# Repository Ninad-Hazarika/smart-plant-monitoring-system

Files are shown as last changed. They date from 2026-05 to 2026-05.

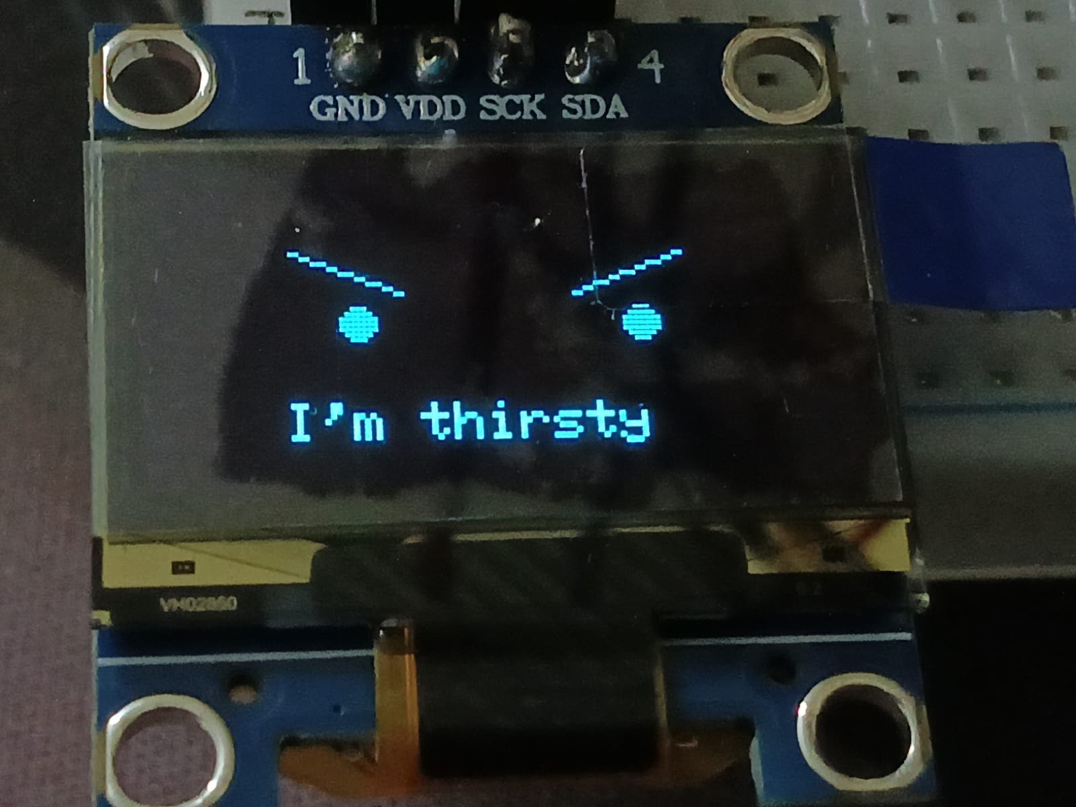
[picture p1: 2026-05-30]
smart-plant-monitoring-system/Images/thirsty_eyes.jpeg

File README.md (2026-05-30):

<div align="center">

```
 ██████╗ ██████╗ ███████╗███████╗███╗   ██╗    ██████╗ ██╗      █████╗ ███╗   ██╗████████╗
██╔════╝ ██╔══██╗██╔════╝██╔════╝████╗  ██║    ██╔══██╗██║     ██╔══██╗████╗  ██║╚══██╔══╝
██║  ███╗██████╔╝█████╗  █████╗  ██╔██╗ ██║    ██████╔╝██║     ███████║██╔██╗ ██║   ██║   
██║   ██║██╔══██╗██╔══╝  ██╔══╝  ██║╚██╗██║    ██╔═══╝ ██║     ██╔══██║██║╚██╗██║   ██║   
╚██████╔╝██║  ██║███████╗███████╗██║ ╚████║    ██║     ███████╗██║  ██║██║ ╚████║   ██║   
 ╚═════╝ ╚═╝  ╚═╝╚══════╝╚══════╝╚═╝  ╚═══╝    ╚═╝     ╚══════╝╚═╝  ╚═╝╚═╝  ╚═══╝   ╚═╝   
```

<h1>🌿 Smart Plant Monitoring System</h1>

**ESP32 · IoT · Telegram Alerts · Emotional OLED · Real-Time Web Dashboard**





[]()
[]()

<br/>

> *"Your plant now has feelings — and a Telegram account."*

<br/>

**A full-stack, sensor-fused plant care station** built on ESP32. It monitors soil moisture, ambient temperature & humidity, and water tank level in real time. It controls irrigation automatically or manually via a live web dashboard, fires Telegram push alerts for critical events, reacts to human presence via IR sensing, responds to touch gestures, and expresses five distinct emotions on an OLED face — complete with animated eyes.

</div>

---

## 🧠 System Architecture

```
╔══════════════════════════════════════════════════════════════════════════════╗
║                            SENSOR FUSION LAYER                               ║
║                                                                              ║
║  ┌──────────┐  ┌──────────┐  ┌──────────────┐  ┌──────────┐  ┌──────────┐  ║
║  │  DHT11   │  │   Soil   │  │  Ultrasonic  │  │    IR    │  │  Touch   │  ║
║  │ Temp/Hum │  │ Moisture │  │  HC-SR04     │  │ Detector │  │  Sensor  │  ║
║  │ GPIO 13  │  │ GPIO 34  │  │ TRIG:26 ECHO:25│ │ GPIO 33  │  │ GPIO 32  │  ║
║  └────┬─────┘  └────┬─────┘  └──────┬───────┘  └────┬─────┘  └────┬─────┘  ║
╚═══════╪═════════════╪═══════════════╪════════════════╪═════════════╪════════╝
        │             │               │                │             │
╔═══════▼═════════════▼═══════════════▼════════════════▼═════════════▼════════╗
║                          ESP32 DevKit (240 MHz)                              ║
║                                                                              ║
║   ┌─────────────────────────────────────────────────────────────────────┐   ║
║   │  Core 0: Wi-Fi Stack + WebServer + Telegram HTTPS Client            │   ║
║   │  Core 1: Sensor Reads · Pump Logic · OLED · IR/Touch · Buzzer      │   ║
║   │  ADC: 12-bit (0–4095) for soil moisture                            │   ║
║   │  I2C: GPIO 21 (SDA) / GPIO 22 (SCL) for OLED                      │   ║
║   └─────────────────────────────────────────────────────────────────────┘   ║
╚════════╪══════════════════════════════════╪═══════════════════════╪══════════╝
         │                                  │                       │
╔════════▼═══════════╗            ╔══════════▼═══════╗    ╔═════════▼══════════╗
║   OUTPUT LAYER     ║            ║   CONTROL LAYER  ║    ║  NOTIFICATION      ║
║                    ║            ║                  ║    ║  LAYER             ║
║  ┌──────────────┐  ║            ║  ┌────────────┐  ║    ║  ┌──────────────┐  ║
║  │  OLED 128×64 │  ║            ║  │   Relay    │  ║    ║  │  Telegram    │  ║
║  │  Emotions +  │  ║            ║  │  GPIO 15   │──╫──▶ ║  │  Bot Alerts  │  ║
║  │  Sensor data │  ║            ║  └─────┬──────┘  ║    ║  │  via HTTPS   │  ║
║  └──────────────┘  ║            ║        ▼          ║    ║  └──────────────┘  ║
║  ┌──────────────┐  ║            ║  ┌────────────┐  ║    ║  ┌──────────────┐  ║
║  │    Buzzer    │  ║            ║  │ Water Pump │  ║    ║  │  Web Server  │  ║
║  │  GPIO 27     │  ║            ║  │ (9V ext.)  │  ║    ║  │  Port 80     │  ║
║  └──────────────┘  ║            ║  └────────────┘  ║    ║  │  Dashboard   │  ║
╚════════════════════╝            ╚══════════════════╝    ║  └──────────────┘  ║
                                                          ╚════════════════════╝
```

---

## ✨ Feature Matrix

| Feature | Implementation | Status |
|---|---|:---:|
| 🌱 **Soil Moisture Sensing** | 12-bit ADC on GPIO 34, auto-threshold pump trigger | ✅ |
| 🌡️ **Temperature & Humidity** | DHT11 on GPIO 13, NaN-safe reads | ✅ |
| 💧 **Water Tank Level** | HC-SR04 ultrasonic, distance → level mapping | ✅ |
| 🖥️ **Live OLED Display** | Sensor data + 5 animated face emotions | ✅ |
| 🔌 **Relay Pump Control** | Active-LOW relay, 3 modes: AUTO / MANUAL ON / MANUAL OFF | ✅ |
| 🌐 **Local Web Dashboard** | ESP32-hosted HTTP server, auto-refresh every 2s | ✅ |
| 📱 **Mobile-Responsive UI** | Dark-theme dashboard, progress bars, live sensor cards | ✅ |
| 📲 **Telegram Bot Alerts** | HTTPS push alerts: low water, pump timeout, plant thirsty, human detected | ✅ |
| 👁️ **IR Human Detection** | GPIO 33 PIR/IR sensor, greeting emotion + Telegram ping | ✅ |
| 👆 **Triple-Touch Gesture** | GPIO 32 touch, 3 taps → LAUGHING emotion | ✅ |
| 🔔 **Buzzer Alert** | Beeps when water tank ≤ 3 cm | ✅ |
| 😊 **Emotion Engine** | 5 states: GREETING · HAPPY · SAD · LAUGHING · SLEEPY | ✅ |
| ⏱️ **Smart Alert Cooldowns** | 30s global Telegram cooldown, 5s human alert cooldown | ✅ |
| 🕐 **NTP Time Sync** | pool.ntp.org time sync on boot | ✅ |

---

## 😊 Emotion Engine

The OLED doesn't just show data — the plant *reacts* to the world around it.

```
┌─────────────────────────────────────────────────────────────────────────┐
│                         EMOTION STATE MACHINE                            │
│                                                                          │
│   IR detects human ──────────────────▶  GREETING  "Hello!"             │
│          │                               (3 sec)                        │
│          │                                                               │
│   Pump turns ON (auto or manual) ──────▶  HAPPY   "Ahh... Water!"      │
│                                            (3 sec)                       │
│                                                                          │
│   Water level ≤ 3 cm ──────────────────▶   SAD    "I'm thirsty"        │
│          │                               (3 sec, repeats every 10s)     │
│          │                                                               │
│   3 rapid touches (< 900ms apart) ─────▶ LAUGHING "Hehehe!"            │
│                                            (5 sec)                       │
│                                                                          │
│   No human for 60 seconds ─────────────▶  SLEEPY  "Zzz..."             │
│                                            (3 sec)                       │
│                                                                          │
│   Any emotion expires ─────────────────▶   NONE   [Sensor Data Screen] │
└─────────────────────────────────────────────────────────────────────────┘
```

### OLED Eye Animations

```
  OPEN EYES         HAPPY EYES        SAD EYES          SLEEPY EYES
  (Greeting)        (Watered)         (Thirsty)         (Idle 60s)

  ╭───╮ ╭───╮      ╱╲    ╱╲         ╲    ╱             ────  ────
  │ ● │ │ ● │     ╱  ╲  ╱  ╲         ╲  ╱                            Zz
  ╰───╯ ╰───╯                          ╲╱            (half-closed)
                                      • •
  LAUGHING
  ╱╲    ╱╲
 ╱  ╲  ╱  ╲    ←  happy eyes
  ╲──────╱      ←  wide grin
```

---

## 📲 Telegram Alert System

The bot fires push notifications directly to your phone. No polling — purely event-driven with smart cooldowns to prevent spam.

```
┌────────────────────────────────────────────────────────────────────┐
│                     ALERT TRIGGER CONDITIONS                        │
├─────────────────────────┬──────────────────────┬───────────────────┤
│ Alert                   │ Trigger Condition     │ Cooldown          │
├─────────────────────────┼──────────────────────┼───────────────────┤
│ 💧 Low Water            │ Tank level ≤ 3 cm     │ Once per event    │
│ ⚠️  Pump Running Long   │ Pump ON > 60 seconds  │ Once per event    │
│ 🌵 Plant Thirsty        │ Soil dry + pump OFF   │ Once per event    │
│                         │ for > 60 seconds      │                   │
│ 👤 Human Detected       │ IR sensor triggered   │ 5 seconds         │
│ ✅ System Online        │ On boot               │ Once              │
└─────────────────────────┴──────────────────────┴───────────────────┘
```

**Setup your Telegram bot:**

```
1. Open Telegram → search @BotFather
2. Send /newbot → follow prompts → copy your Bot Token
3. Add your bot to a group OR get your Chat ID via @userinfobot
4. Edit these lines in smart_plant_monitoring.ino:

   String botToken = "YOUR_BOT_TOKEN_HERE";
   String chatID   = "YOUR_CHAT_ID_HERE";
```

---

## 🌐 Web Dashboard

The ESP32 hosts a full dark-themed dashboard on port 80. No internet required — works entirely on your local Wi-Fi.

```
╔═══════════════════════════════════════════╗
║        SMART PLANT DASHBOARD              ║
║                        192.168.x.x        ║
╠═══════════════════════════════════════════╣
║  SENSORS                                  ║
║  ┌───────────────┐  ┌───────────────┐     ║
║  │ Soil Moisture │  │ Temperature   │     ║
║  │    2847       │  │   28.5 °C     │     ║
║  │ ████████░░░░  │  │ ██████░░░░░░  │     ║
║  └───────────────┘  └───────────────┘     ║
║  ┌───────────────┐  ┌───────────────┐     ║
║  │  Humidity     │  │ Water Level   │     ║
║  │   65.0 %      │  │   9.2 cm      │     ║
║  │ ████████████░ │  │ ████████████░ │     ║
║  └───────────────┘  └───────────────┘     ║
╠═══════════════════════════════════════════╣
║  PUMP CONTROL                             ║
║  Pump is OFF  ·  AUTO MODE                ║
║  ✅ System running normally               ║
║                                           ║
║  ╔══════╗  ╔══════╗  ╔══════╗            ║
║  ║  ON  ║  ║  OFF ║  ║ AUTO ║            ║
║  ╚══════╝  ╚══════╝  ╚══════╝            ║
╠═══════════════════════════════════════════╣
║  Auto-refreshes every 2 seconds           ║
╚═══════════════════════════════════════════╝

  Endpoints:
  GET /             → Full dashboard
  GET /pump/on      → Force pump ON  (MANUAL mode)
  GET /pump/off     → Force pump OFF (MANUAL mode)
  GET /pump/auto    → Return to AUTO mode
```

---
## 🎨 CAD Design

The complete enclosure and product body for the Smart Plant Monitoring System was designed using Onshape.

📁 View CAD Files Here → [CAD Design](./CAD-Design)

---
## 🛠️ Hardware & Bill of Materials

```
┌─────────────────────────────────────────────────────────────────────┐
│  COMPONENT                   │  QTY │  GPIO       │  PURPOSE        │
├──────────────────────────────┼──────┼─────────────┼─────────────────┤
│  ESP32 DevKit v1             │   1  │  —          │  MCU + Wi-Fi    │
│  DHT11 Sensor                │   1  │  GPIO 13    │  Temp + Humidity│
│  Capacitive Soil Sensor      │   1  │  GPIO 34    │  Soil moisture  │
│  HC-SR04 Ultrasonic          │   1  │  TRIG: 26   │  Tank level     │
│                              │      │  ECHO: 25   │                 │
│  OLED SSD1306 (0.96" I2C)   │   1  │  SDA: 21    │  Display/face   │
│                              │      │  SCL: 22    │                 │
│  5V Relay Module             │   1  │  GPIO 15    │  Pump switch    │
│  Mini DC Water Pump          │   1  │  (via relay)│  Irrigation     │
│  IR Obstacle/PIR Sensor      │   1  │  GPIO 33    │  Human detect   │
│  Touch Sensor Module         │   1  │  GPIO 32    │  Gesture input  │
│  Passive Buzzer              │   1  │  GPIO 27    │  Tank low alert │
│  9V Battery or DC Adapter    │   1  │  —          │  Pump power     │
│  USB Micro Cable             │   1  │  —          │  Program + 3.3V │
│  Jumper Wires (assorted)     │ ~30  │  —          │  Connections    │
│  Breadboard / Custom PCB     │   1  │  —          │  Assembly       │
└──────────────────────────────┴──────┴─────────────┴─────────────────┘
```

> **💡 Tip:** Use a **capacitive** soil moisture sensor over resistive — it doesn't corrode in wet soil and gives more stable analog readings.

---

## 🔌 Complete Pin Wiring Reference

```
                    ┌─────────────────────────┐
                    │       ESP32 DevKit       │
         DHT11 ────▶│ GPIO13          GPIO26  │────▶ HC-SR04 TRIG
    Soil Sensor ───▶│ GPIO34          GPIO25  │◀──── HC-SR04 ECHO
     Relay IN  ────▶│ GPIO15          GPIO27  │────▶ Buzzer (+)
      OLED SDA ────▶│ GPIO21          GPIO33  │◀──── IR Sensor OUT
      OLED SCL ────▶│ GPIO22          GPIO32  │◀──── Touch Sensor
          3.3V ────▶│ 3V3             GND     │────▶ Common GND
           VIN ────▶│ VIN (5V)                │
                    └─────────────────────────┘
```

| Peripheral | Signal | GPIO | Logic |
|---|---|:---:|---|
| **DHT11** | Data | `13` | 3.3V, add 10kΩ pull-up if needed |
| **Soil Sensor** | Analog OUT | `34` | Input-only ADC pin, 12-bit |
| **HC-SR04** | TRIG | `26` | 10µs pulse to trigger |
| **HC-SR04** | ECHO | `25` | pulseIn() measures duration |
| **OLED SSD1306** | SDA | `21` | I2C data, address 0x3C |
| **OLED SSD1306** | SCL | `22` | I2C clock |
| **Relay** | IN | `15` | Active LOW (RELAY_ON = LOW) |
| **IR Sensor** | OUT | `33` | LOW = human/object detected |
| **Touch Sensor** | OUT | `32` | HIGH = touch detected |
| **Buzzer** | + | `27` | digitalWrite HIGH to sound |

> ⚠️ **Critical:** Never power the water pump from ESP32 GPIO. Always use the relay as an isolated switch with a dedicated 9V supply. Connect the negative terminals (GND) of both supplies together.

---

## 📂 Repository Structure

```
smart-plant-monitoring-system/
│
├── 📄 README.md                        ← You are here
├── 📄 LICENSE                          ← MIT License
├── 📄 .gitignore
│
├── 📁 src/
│   ├── 🔧 smart_plant_monitoring.ino   ← Main firmware (FULL system)
│   ├── 🧪 pump_relay_test.ino          ← Isolated relay/pump test
│   └── 🧪 sensor_test.ino             ← DHT11 + soil sensor test
│
├── 📁 hardware/
│   ├── 📋 component_list.md            ← Full BOM with specs
│   └── 🔌 wiring_guide.md             ← Step-by-step connections
│
├── 📁 schematics/
│   └── 📐 README.md                   ← EasyEDA schematic notes
│
├── 📁 pcb/
│   └── 🖨️ README.md                   ← PCB design & fabrication guide
│
├── 📁 docs/
│   └── 📃 project_report.md           ← Technical project report
│
├── 📁 images/
│   └── 🖼️ (add project photos here)
│
└── 📁 website/
    └── 🌐 index.html                  ← Standalone web UI reference
```

---

## 📦 Required Arduino Libraries

Install via **Arduino IDE → Sketch → Include Library → Manage Libraries**:

```
┌─────────────────────────────────────────────────────────────────────┐
│  LIBRARY                     │  AUTHOR     │  PURPOSE               │
├──────────────────────────────┼─────────────┼────────────────────────┤
│  Adafruit GFX Library        │  Adafruit   │  OLED graphics engine  │
│  Adafruit SSD1306            │  Adafruit   │  OLED I2C driver       │
│  DHT sensor library          │  Adafruit   │  DHT11/22 driver       │
│  Adafruit Unified Sensor     │  Adafruit   │  Sensor abstraction    │
│  WiFi (built-in)             │  Espressif  │  Wi-Fi stack           │
│  WebServer (built-in)        │  Espressif  │  HTTP server           │
│  HTTPClient (built-in)       │  Espressif  │  Telegram HTTPS calls  │
│  WiFiClientSecure (built-in) │  Espressif  │  TLS/SSL for Telegram  │
└──────────────────────────────┴─────────────┴────────────────────────┘
```

**ESP32 Board Package** (add to Arduino IDE → Boards Manager URLs):
```
https://raw.githubusercontent.com/espressif/arduino-esp32/gh-pages/package_esp32_index.json
```

---

## 🚀 Getting Started

### 1. Clone the Repository

```bash
git clone https://github.com/YOUR_USERNAME/smart-plant-monitoring-system.git
cd smart-plant-monitoring-system
```

### 2. Configure Credentials

Open `src/smart_plant_monitoring.ino` and edit these lines:

```cpp
// Wi-Fi credentials
const char* ssid     = "YOUR_WIFI_NAME";
const char* password = "YOUR_WIFI_PASSWORD";

// Telegram bot (see Telegram Setup section above)
String botToken = "YOUR_BOT_TOKEN";
String chatID   = "YOUR_CHAT_ID";

// Calibration
int threshold   = 3000;    // ADC value above which soil is "dry"
float tankHeight = 13.7;   // Height of your water tank in cm
```

### 3. Upload to ESP32

```
1. Open src/smart_plant_monitoring.ino in Arduino IDE
2. Tools → Board → ESP32 Arduino → "ESP32 Dev Module"
3. Tools → Port → Select your COM port
4. Tools → Upload Speed → 115200
5. Click Upload ▶
6. Open Serial Monitor at 115200 baud
7. Wait for "WiFi Connected" and note the IP address
8. Open that IP in any browser on the same Wi-Fi
```

### 4. Test Components Individually

Before running the full system, verify hardware with isolated tests:

```
Relay/Pump Test:   src/pump_relay_test.ino
                   → Pump toggles ON/OFF every 3 seconds

Sensor Test:       src/sensor_test.ino
                   → Soil, temperature, humidity printed to Serial every 1s
```

---

## ⚙️ Pump Control Modes

```
┌──────────────────────────────────────────────────────────────────┐
│  MODE         │  BEHAVIOR                          │  pumpMode   │
├───────────────┼────────────────────────────────────┼─────────────┤
│  AUTO         │  Pump ON if soilValue > threshold  │     0       │
│               │  Pump OFF when soil is moist again │             │
├───────────────┼────────────────────────────────────┼─────────────┤
│  MANUAL ON    │  Pump forced ON regardless of soil │     1       │
│               │  HAPPY emotion triggered on switch │             │
├───────────────┼────────────────────────────────────┼─────────────┤
│  MANUAL OFF   │  Pump forced OFF regardless        │     2       │
└───────────────┴────────────────────────────────────┴─────────────┘
```

---

## 📈 Sensor Data Reference

### Soil Moisture ADC Scale (GPIO 34, 12-bit)

```
  WET  ░░░░░░░░░░░░░░░░░████████████████  0    – 1500
  MOIST░░░░░░░░████████████████░░░░░░░░░  1500 – 3000
  DRY  ████████████████████░░░░░░░░░░░░░  3000 – 4095  ← pump triggers here

  Default dryThreshold = 3000  (calibrate for your soil + sensor type)
  Lower reading = more water in soil (inverse relationship)
```

### DHT11 Operating Ranges

```
  Temperature :  0°C – 50°C    (±2°C accuracy)
  Humidity    :  20% – 90% RH  (±5% accuracy)
  Sample rate :  1 Hz max       (1 reading/second)
  Power       :  3.3V or 5V
```

### HC-SR04 Water Level Formula

```
  distance (cm) = pulseIn(ECHO, HIGH) × 0.034 / 2
  waterLevel    = tankHeight − distance

  tankHeight = physical height of tank (default: 13.7 cm)
  waterLevel = 0 when empty, tankHeight when full
  Alert fires when waterLevel ≤ 3 cm
```

---

## 🧠 Firmware Loop Overview

```
BOOT
 │
 ├─ Init: Serial, GPIO, DHT, OLED, Wi-Fi, WebServer, NTP
 ├─ Send Telegram: "SMART_PLANT_SYSTEM_ONLINE"
 │
 └─ LOOP (every 50ms)
      │
      ├─ server.handleClient()         ← serve web dashboard requests
      │
      ├─ handleIR()                    ← detect human → GREETING emotion
      ├─ handleTouch()                 ← 3 taps → LAUGHING emotion
      │
      └─ (every 1000ms)
           ├─ readSoil()               ← ADC read GPIO 34
           ├─ readDHT()                ← temperature + humidity
           ├─ readWaterLevel()         ← HC-SR04 pulse timing
           ├─ controlPump()            ← AUTO / MANUAL logic + relay
           ├─ checkTankLevel()         ← buzzer beep if water ≤ 3cm
           ├─ updateOLED()             ← emotion or sensor data screen
           └─ checkTelegramAlerts()    ← push alerts with cooldowns
```

---

## 🔭 Roadmap

- [x] Soil moisture sensing + auto pump control
- [x] DHT11 temperature & humidity
- [x] HC-SR04 water tank level monitoring
- [x] OLED animated emotion display
- [x] Relay pump: AUTO / MANUAL ON / MANUAL OFF modes
- [x] Local Wi-Fi web dashboard (dark theme, auto-refresh)
- [x] Telegram bot alerts (low water, pump timeout, thirsty, human)
- [x] IR human detection + greeting emotion
- [x] Triple-touch gesture → laughing emotion
- [x] Buzzer low-water alert
- [x] NTP time synchronization
- [ ] MQTT / Home Assistant integration
- [ ] Data logging to SD card or Firebase
- [ ] OTA (Over-The-Air) firmware updates
- [ ] Battery backup with solar charging
- [ ] Custom PCB with enclosure
- [ ] Daily summary Telegram report

---

## 🤝 Contributing

1. Fork the repository
2. Create a feature branch: `git checkout -b feature/mqtt-integration`
3. Commit your changes: `git commit -m 'Add MQTT support for Home Assistant'`
4. Push the branch: `git push origin feature/mqtt-integration`
5. Open a Pull Request

---

## 👤 Author

**Ninad Hazarika**  
📧 [ninadhazarika@gmail.com](mailto:ninadhazarika@gmail.com)  
🌍 Built with curiosity, an ESP32, and a slightly dramatic plant 🌱

---

## 📜 License

This project is licensed under the **MIT License** — see the [LICENSE](./LICENSE) file for details.

---

<div align="center">

**⭐ Found this useful? Star the repo and share it with a fellow plant parent!**

```
        .     .
       /|\   /|\
      / | \ / | \
     /  |  X  |  \
    / 🌡️ |/ \| 💧 \
   /    |   |    \
  /_____|___|_____\
  | 🌿 SMART  🌿 |
  |  PLANT LOVE  |
  |______________|
```

*For every plant that ever wilted because no one was watching.*  
*Not anymore.* 🌿

</div>

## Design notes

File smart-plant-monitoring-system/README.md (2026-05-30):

# 🌱 Smart Plant Monitoring System

A smart IoT-based plant monitoring and irrigation system developed using ESP32. The project monitors environmental conditions such as soil moisture, temperature, and humidity, and can automatically control water supply to plants when required.

## 📌 Features

* Real-time soil moisture monitoring
* Temperature and humidity sensing using DHT11
* Automatic irrigation using relay-controlled water pump
* OLED display for local monitoring
* Human detection alerts using IR sensor
* Wi-Fi connectivity through ESP32
* Telegram notifications for remote monitoring
* Custom PCB design for hardware integration
* 3D CAD enclosure design for project assembly

## 🛠️ Hardware Components

* ESP32 Development Board
* Soil Moisture Sensor
* DHT11 Temperature & Humidity Sensor
* OLED Display (128×64)
* Relay Module
* Mini Water Pump
* IR Sensor
* LEDs and Resistors
* Power Supply
* Connecting Wires

## 💻 Software & Tools

* Arduino IDE
* EasyEDA (Schematic & PCB Design)
* Onshape (CAD Design)
* Git & GitHub

## 📂 Repository Structure

├── Arduino-Code
├── PCB-Design
├── CAD-Design
├── Images
├── Project-Report
└── README.md

## ⚙️ Working Principle

The soil moisture sensor continuously monitors the moisture level of the soil. When the moisture level drops below a predefined threshold, the ESP32 activates a relay that powers the water pump and irrigates the plant automatically.

Environmental data from the DHT11 sensor is displayed on the OLED screen. The system can also send notifications through Telegram and provide remote monitoring capabilities via Wi-Fi.

## 📸 Project Gallery

Screenshots, hardware setup images, PCB layouts, CAD models, and demonstration photographs can be found in the Images folder.

## 🚀 Future Improvements

* Mobile application integration
* Cloud-based data logging
* Weather-aware irrigation scheduling
* AI-powered plant health monitoring
* Battery and solar-powered operation

## 👨‍💻 Author

Ninad Hazarika

Electronics and Communication Engineering Student

Tezpur University

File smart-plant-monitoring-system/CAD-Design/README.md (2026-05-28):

# 🌱 Smart Plant Monitoring System - CAD Design

This folder contains the complete CAD design and enclosure development for the Smart Plant Monitoring System created using Onshape.

---

## 📌 Design Objectives

- Create a compact smart planter enclosure
- Integrate electronics safely inside the body
- Design dedicated water tank placement
- Create proper routing space for wiring
- Ensure easy accessibility for maintenance
- Build an aesthetic and functional product design

---

## 🛠 Designed Components

### 🌿 Plant Holder
- Dedicated space for soil and plant placement
- Stable and compact structure

### 💧 Water Tank
- Separate compartment for water storage
- Optimized for mini water pump integration

### ⚡ Electronics Section
- Placement for:
  - ESP32
  - Relay Module
  - Soil Moisture Sensor
  - DHT11 Sensor
  - OLED Display
  - Wiring Management

### 🔩 Enclosure Design
- Compact all-in-one body
- Practical layout for real-world usage

---

## 🧰 Software Used

- Onshape CAD

---

## 📂 Included Files

| File Type | Description |
|---|---|
| `.STEP` | Complete 3D assembly |
| `.STL` | 3D printable model |
| `.PNG` | Design previews and renders |

---

## 📸 CAD Preview

### Full Assembly
Full Assembly

### Exploded View
Exploded View

### Electronics Placement
Electronics

---

## 🚀 Future Improvements

- Waterproof enclosure
- Better cable management
- Modular sensor slots
- Optimized 3D printable design

---

## 👨‍💻 Developed By

Ninad Hazarika

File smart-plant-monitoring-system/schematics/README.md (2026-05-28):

# Schematics

Circuit schematics for the Smart Plant Monitoring System were designed using [EasyEDA](https://easyeda.com/).

## Files Added

| Format | Use |
|---|---|
| `.svg` | Preview in GitHub directly |
| `.json` | EasyEDA native project file |
| `.pdf` | High-res printable schematic |
| `.png` | Quick documentation embed |

## Key Connections Summary

- **DHT11** → GPIO 13 (data), 3.3V, GND
- **Soil Sensor** → GPIO 34 (analog), 3.3V, GND
- **OLED SSD1306** → GPIO 21 (SDA), GPIO 22 (SCL), 3.3V, GND
- **Relay** → GPIO 15 (IN), 5V/VIN, GND
- **Pump** → Relay COM/NO terminals, powered by external 9V supply

See `hardware/wiring_guide.md` for the complete step-by-step guide.

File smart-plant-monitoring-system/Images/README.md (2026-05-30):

# Images

This directory contains screenshots, photographs, PCB layouts, CAD designs, and demonstration images for the Smart Plant Monitoring System project.

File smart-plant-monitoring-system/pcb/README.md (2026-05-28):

# PCB Design

Custom PCB layout for the Smart Plant Monitoring System.

## Design Tool

PCB was designed in [EasyEDA](https://easyeda.com/) — free, browser-based, with direct JLCPCB/PCBWay ordering integration.

## Files Added Here

| File | Description |
|---|---|
| `pcb_design.json` | EasyEDA PCB project file |
| `gerber.zip` | Gerber files for PCB fabrication |
| `pcb_top.png` | Top layer render |
| `pcb_bottom.png` | Bottom layer render |

## PCB Ordering

Export Gerber files from EasyEDA and upload to:
- [JLCPCB](https://jlcpcb.com/) — ~$2 for 5 PCBs
- [PCBWay](https://www.pcbway.com/)

## Design Notes

- Ensure relay footprint matches your specific relay module dimensions
- Add decoupling capacitor (100nF) near ESP32 3.3V pin
- Route I2C lines (SDA/SCL) with short traces to minimize interference
- Separate pump power ground from ESP32 signal ground if possible

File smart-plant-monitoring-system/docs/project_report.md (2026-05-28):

# Project Report: Smart Plant Monitoring System

## Introduction

This project is an ESP32-based smart plant monitoring and irrigation system. It reads soil moisture, temperature, and humidity, displays values on an OLED screen, and controls a water pump through a relay.

## Objective

The goal is to create a low-cost plant care system that can help monitor plant health and automate watering.

## Methodology

1. Connect sensors to ESP32.
2. Read sensor values using Arduino IDE.
3. Display readings on OLED.
4. Control pump using relay.
5. Add Wi-Fi web interface for phone-based control.
6. Design schematic and PCB using EasyEDA.

## Result

The system successfully reads sensor values and allows pump control through a local web page.

## Conclusion

This project helped demonstrate the use of ESP32, sensors, relay modules, OLED display, and basic IoT control.

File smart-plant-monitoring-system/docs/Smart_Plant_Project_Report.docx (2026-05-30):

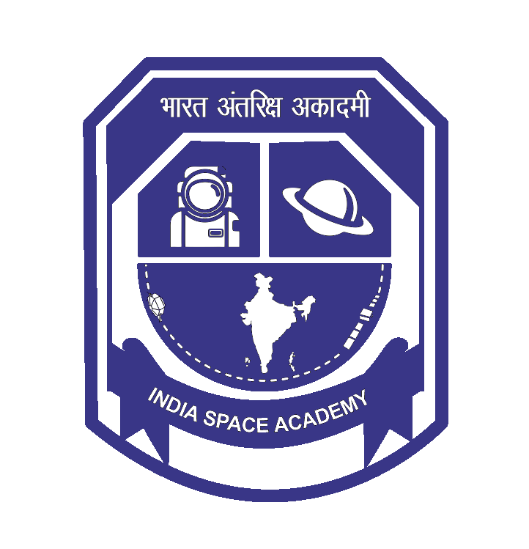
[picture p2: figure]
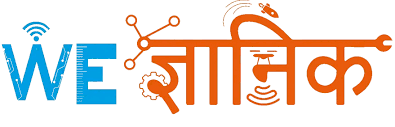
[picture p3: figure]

PROJECT REPORT

Smart Plant Monitoring System

ESP32-Powered IoT Plant Care & Automation System

Author | Ninad Hazarika
Email | ninadhazarika@gmail.com
IDE | Arduino IDE 2.x
Language | C++ (Arduino Framework)
Version | v2.0 — 2026
License | MIT Open Source

https://github.com/Ninad-Hazarika/smart-plant-monitoring-system

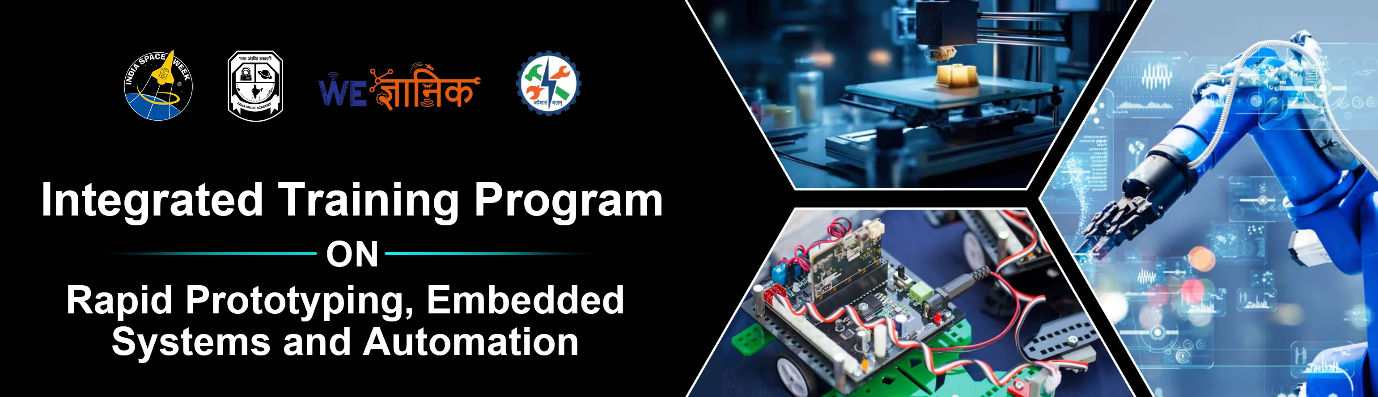
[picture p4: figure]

# 1. Project Title & Introduction

## 1.1 Project Title

Smart Plant Monitoring System using ESP32

## 1.2 Introduction

Modern agriculture and home gardening face a persistent challenge: plants are frequently over-watered, under-watered, or neglected due to busy schedules and the absence of objective feedback. Traditional plant care relies entirely on human observation — a method prone to error, inconsistency, and forgetfulness.

This project presents a fully autonomous, IoT-enabled Smart Plant Monitoring System built on the ESP32 microcontroller. The system continuously measures soil moisture, ambient temperature and humidity, and water tank level. It drives a relay-controlled irrigation pump automatically based on configurable soil dryness thresholds, hosts a live dark-theme web dashboard accessible from any browser on the local network, and fires real-time push alerts directly to the user's Telegram account for five distinct critical events.

Beyond pure telemetry, the system incorporates a personality layer: an OLED display renders animated facial expressions that react to environmental conditions and human presence — greeting visitors through IR detection, expressing happiness when watered, sadness when the tank runs low, and playful laughter when a triple-touch gesture is detected.

Key Highlights at a Glance:

• 9 peripherals fused on a single ESP32 — sensors, actuators, display, network

• Three pump modes: AUTO (soil-threshold) / MANUAL ON / MANUAL OFF

• 5-state animated OLED emotion engine

• Real-time Telegram bot push alerts over HTTPS

• Local Wi-Fi web dashboard — no cloud required

# 2. Problem Statement

The following core problems motivate the design of this system:

- Inconsistent manual watering causes root rot (over-watering) or wilting (under-watering), both of which cause lasting damage to plant health.
- The absence of real-time sensor feedback means the user has no objective data to inform watering decisions.
- Water tank depletion goes undetected — automated pump systems run dry, damaging the pump and failing to irrigate the plant.
- No alert mechanism means problems are only discovered after visible damage has already occurred.
- Human presence near sensitive plants goes unlogged, which matters in shared spaces or research environments.

The proposed solution addresses all five problems through sensor fusion, rule-based automation, and real-time communication — requiring zero manual intervention under normal operating conditions.

# 3. Components Used

## 3.1 Bill of Materials

Component | Specification | Qty | GPIO / Interface | Purpose
ESP32 DevKit v1 | Dual-core LX6, 240 MHz, Wi-Fi + BT | 1 | — | Main MCU + network
DHT11 Sensor | 0-50 C, 20-90% RH, digital 1-wire | 1 | GPIO 13 | Temp & humidity
Soil Moisture Sensor | Capacitive, analog, 3.3V | 1 | GPIO 34 (ADC) | Soil wetness 0-4095
HC-SR04 Ultrasonic | 2-400 cm, +/-3 mm, 5V | 1 | TRIG:26 ECHO:25 | Water tank level
OLED SSD1306 | 0.96", 128x64 px, I2C, 3.3V | 1 | SDA:21 SCL:22 | Live display + face
5V Relay Module | Single ch., active LOW, 10A/250VAC | 1 | GPIO 15 | Pump switching
Mini DC Water Pump | 3-6V, submersible, ~100 L/h | 1 | Via relay | Irrigation
IR Obstacle Sensor | Digital OUT, adjustable detection range | 1 | GPIO 33 | Human detection
Touch Sensor (TTP223) | Capacitive, digital OUT, 3.3-5V | 1 | GPIO 32 | Gesture input
Passive Buzzer | 5V, ~2 kHz | 1 | GPIO 27 | Low-water alert
9V Adapter / Battery | Isolated pump supply | 1 | — | Pump power
USB Micro Cable | Programming + ESP32 power | 1 | — | Development
Jumper Wires | M-M / M-F assorted | ~30 | — | Wiring
Breadboard / PCB | 830-point or custom EasyEDA PCB | 1 | — | Assembly

## 3.2 Library Dependencies

Library | Author | Purpose
Adafruit GFX Library | Adafruit | OLED graphics primitives (circles, lines, text)
Adafruit SSD1306 | Adafruit | SSD1306 OLED driver over I2C
DHT sensor library | Adafruit | DHT11 / DHT22 one-wire protocol driver
Adafruit Unified Sensor | Adafruit | Unified hardware abstraction layer
WiFi (built-in) | Espressif | Wi-Fi station mode and connection management
WebServer (built-in) | Espressif | HTTP server on port 80 for web dashboard
HTTPClient (built-in) | Espressif | HTTPS GET client for Telegram Bot API
WiFiClientSecure (built-in) | Espressif | TLS/SSL transport for Telegram HTTPS calls

# 4. Working Explanation

## 4.1 System Boot Sequence

On power-up the ESP32 initialises all GPIO pins, starts the DHT11 driver, initialises the OLED display and shows a startup message, connects to Wi-Fi, synchronises time via NTP (pool.ntp.org), starts the HTTP web server on port 80, and transmits a 'System Online' Telegram notification. The full boot sequence completes in approximately 5-7 seconds.

## 4.2 Main Execution Loop

The main loop executes with a 50 ms base delay. Work is divided into per-loop and per-second tasks:

### Every iteration (50 ms):

- server.handleClient() — serves incoming HTTP requests from browsers
- handleIR() — polls GPIO 33; detects human presence on LOW signal; triggers GREETING emotion on rising edge
- handleTouch() — polls GPIO 32; tracks rapid triple-tap within 900 ms window to trigger LAUGHING emotion

### Every 1000 ms (sensor cycle):

- readSoil() — 12-bit ADC read on GPIO 34 (higher value = drier soil)
- readDHT() — reads temperature and humidity from DHT11 with NaN protection
- readWaterLevel() — sends 10 µs TRIG pulse; measures ECHO duration; computes: waterLevel = tankHeight - (duration x 0.034 / 2)
- controlPump() — evaluates pumpMode and drives relay accordingly; triggers HAPPY on pump start
- checkTankLevel() — pulses buzzer on GPIO 27 if waterLevel is at or below 3 cm
- updateOLED() — renders active emotion face or sensor data screen
- checkTelegramAlerts() — evaluates all five alert conditions with independent cooldown timers

## 4.3 Pump Control Modes

Mode | pumpMode | Behaviour | Emotion
AUTO | 0 | Pump ON when soilValue > threshold; OFF when moist again | HAPPY when pump first turns ON
MANUAL ON | 1 | Pump forced ON regardless of soil moisture reading | HAPPY immediately
MANUAL OFF | 2 | Pump forced OFF regardless of soil moisture reading | None

## 4.4 OLED Emotion Engine

The emotion engine uses a priority system: when currentEmotion is not NONE, the OLED renders the face animation. When emotionUntil is exceeded (millis() > emotionUntil), the system returns to NONE and the sensor data screen is shown. Emotion drawing uses Adafruit GFX primitives on the 128x64 pixel canvas.

Emotion | Trigger | Duration | OLED Text
GREETING | IR sensor detects object (rising edge on GPIO 33) | 3 seconds | Hello!
HAPPY | Pump turns ON (auto threshold or manual) | 3 seconds | Ahh... Water!
SAD | Water level at or below 3 cm (repeats every 10s) | 3s per cycle | I'm thirsty
LAUGHING | 3 touch events within 900 ms on GPIO 32 | 5 seconds | Hehehe!
SLEEPY | No IR trigger for 60+ consecutive seconds | 3 seconds | Zzz...
NONE | Any emotion timer expires (emotionUntil exceeded) | Until next event | [Sensor Data Screen]

## 4.5 Telegram Alert System

Alerts are delivered using WiFiClientSecure with setInsecure() to establish TLS sessions with api.telegram.org without certificate pinning. All message text is URL-encoded before embedding in the GET request URL. Five independent alert conditions are checked on every sensor cycle:

Alert | Trigger Condition | Cooldown | Auto-Reset When
System Online | Boot completes | Once | N/A
Low Water | waterLevel at or below 3 cm | Per event | waterLevel > 5 cm
Pump Overtime | Pump ON for more than 60 continuous seconds | Per event | Pump turns OFF
Plant Thirsty | soilValue > threshold AND pump OFF for 60s+ | Per event | Moist OR pump ON
Human Detected | IR LOW for 2+ consecutive loop polls | 5 seconds | IR returns HIGH

## 4.6 Web Dashboard

The ESP32 hosts a single-page dark-theme dashboard on port 80. Sensor values are embedded server-side at render time. The page auto-refreshes every 2 seconds via JavaScript setTimeout(). Pump mode changes are handled as HTTP 303 redirects. The dashboard is fully responsive and works on any mobile or desktop browser on the same Wi-Fi network.

# 5. Circuit Diagram

## 5.1 Complete GPIO Pin Assignment

Peripheral | Peripheral Pin | ESP32 Pin | Signal | Notes
DHT11 | Data OUT | GPIO 13 | Digital 1-wire | Add 10k pull-up if no onboard resistor
DHT11 | VCC | 3.3V | Power
DHT11 | GND | GND | Ground
Soil Sensor | AO | GPIO 34 | Analog ADC | Input-only pin; 12-bit resolution
Soil Sensor | VCC | 3.3V | Power
HC-SR04 | TRIG | GPIO 26 | Digital OUT | 10 µs HIGH pulse to trigger
HC-SR04 | ECHO | GPIO 25 | Digital IN | Use voltage divider if module outputs 5V
OLED SSD1306 | SDA | GPIO 21 | I2C Data | I2C address 0x3C
OLED SSD1306 | SCL | GPIO 22 | I2C Clock
OLED SSD1306 | VCC | 3.3V | Power
Relay Module | IN | GPIO 15 | Digital OUT | Active LOW — RELAY_ON = LOW
Relay Module | VCC | VIN (5V) | Power | Must use 5V, not 3.3V
IR Sensor | OUT | GPIO 33 | Digital IN | LOW = object/human detected
Touch Sensor | OUT | GPIO 32 | Digital IN | HIGH = touch detected
Buzzer | Positive | GPIO 27 | Digital OUT | HIGH = buzzer sounds

## 5.2 Power & Safety Notes

- CRITICAL: Never connect the water pump directly to any ESP32 GPIO pin. The relay provides full galvanic isolation between the 3.3V control circuit and the 9V pump circuit.
- Connect the negative terminal (GND) of the 9V pump supply to the ESP32 GND to create a common ground reference.
- GPIO 34 is an ADC input-only pin — do not attempt to configure it as OUTPUT.
- The HC-SR04 ECHO pin on some modules outputs 5V logic. Use a 1k/2k voltage divider before GPIO 25 to avoid damaging the ESP32.

Schematic & PCB files:

• EasyEDA schematic (.json, .svg) — available in /schematics/ on GitHub

• PCB layout and Gerber files for fabrication — available in /pcb/ on GitHub

• PCB can be ordered from JLCPCB for approximately $2 USD per 5 boards

# 6. Source Code

## 6.1 Repository File Structure

File / Folder | Description
src/smart_plant_monitoring.ino | Main firmware — complete system with all 9 peripherals
src/pump_relay_test.ino | Isolated relay and pump test (toggles every 3 seconds)
src/sensor_test.ino | DHT11 + soil sensor diagnostic (Serial Monitor output)
hardware/component_list.md | Full BOM with specifications and sourcing information
hardware/wiring_guide.md | Step-by-step connection guide for each peripheral
schematics/ | EasyEDA circuit schematic files (.json, .svg)
pcb/ | PCB layout and Gerber files for board fabrication
docs/ | Project report (this document) and technical notes
website/index.html | Standalone web dashboard UI reference file
README.md | Full technical documentation and quick-start guide

## 6.2 Key Code Sections

### Water Level Measurement — HC-SR04

void readWaterLevel() {

digitalWrite(TRIG_PIN, LOW);

delayMicroseconds(2);

digitalWrite(TRIG_PIN, HIGH); // trigger 10us pulse

delayMicroseconds(10);

digitalWrite(TRIG_PIN, LOW);

long duration = pulseIn(ECHO_PIN, HIGH, 30000); // 30ms timeout

if (duration == 0) { waterLevel = -1; return; } // no echo = error

float distance = duration * 0.034 / 2; // convert to cm

waterLevel = tankHeight - distance; // invert: less distance = more water

if (waterLevel < 0) waterLevel = 0;

}

### Three-Mode Pump Control

void controlPump() {

bool oldState = pumpState;

if (pumpMode == 1) { digitalWrite(RELAY_PIN, RELAY_ON); pumpState = true; }

else if (pumpMode == 2) { digitalWrite(RELAY_PIN, RELAY_OFF); pumpState = false; }

else { // AUTO — soil threshold control

if (soilValue > threshold) { digitalWrite(RELAY_PIN, RELAY_ON); pumpState = true; }

else { digitalWrite(RELAY_PIN, RELAY_OFF); pumpState = false; }

}

if (!oldState && pumpState) { // pump just turned ON

currentEmotion = HAPPY;

emotionUntil = millis() + 3000;

}

}

### Triple-Touch Gesture Detection

void handleTouch() {

bool touchState = digitalRead(TOUCH_PIN);

if (touchState == HIGH && lastTouchState == LOW) { // rising edge only

if (millis() - lastTouchTime < 900) touchCount++; // within 900ms window

else touchCount = 1; // too slow, restart count

lastTouchTime = millis();

if (touchCount >= 3) { // triple tap!

currentEmotion = LAUGHING;

emotionUntil = millis() + 5000;

touchCount = 0;

}

}

lastTouchState = touchState;

}

### Telegram HTTPS Push Alert

void sendTelegramMessage(String message) {

if (WiFi.status() != WL_CONNECTED) return;

WiFiClientSecure client;

client.setInsecure(); // TLS without cert pinning (local IoT)

HTTPClient https;

https.setTimeout(15000);

String url = "https://api.telegram.org/bot" + botToken +

"/sendMessage?chat_id=" + chatID +

"&text=" + urlEncode(message);

https.begin(client, url);

int code = https.GET();

https.end();

}

Full source code is available at:

https://github.com/Ninad-Hazarika/smart-plant-monitoring-system

# 7. Testing Results

## 7.1 Individual Component Test Results

Test Case | Method | Expected Outcome | Result
Relay cycle test | pump_relay_test.ino — 3s ON / 3s OFF loop | Relay clicks audibly, pump runs and stops | PASS
DHT11 temperature | Compare with calibrated reference thermometer | Within +/-2 degrees C | PASS
DHT11 humidity | Compare with calibrated reference hygrometer | Within +/-5% RH | PASS
Soil sensor dry | Sensor in open air | ADC reads 3800-4095 | PASS
Soil sensor wet | Probe submerged in water | ADC reads 0-600 | PASS
HC-SR04 level read | Known 5 cm water depth in tank | Reported 5.0 +/- 0.5 cm | PASS
OLED display init | Boot sequence, I2C address scan | Display initialises, shows startup message | PASS
Wi-Fi connection | Serial Monitor at 115200 baud on boot | IP address assigned, dashboard accessible | PASS
Telegram bot online alert | Boot sequence | Message received on Telegram within 10s | PASS
IR human detection | Wave hand in front of sensor | GREETING emotion + Telegram ping fired | PASS
Triple-touch gesture | Tap sensor 3 times within 900ms | LAUGHING emotion triggered for 5 seconds | PASS
Buzzer low water | Set water level to 2 cm during test | Buzzer beeps each sensor cycle | PASS
AUTO pump ON (dry soil) | Cover sensor with dry material above threshold | Pump activates within 1 second | PASS
AUTO pump OFF (wet soil) | Submerge sensor while pump running | Pump stops within 1 second | PASS
Web dashboard access | Open IP in Chrome on mobile and desktop | Dashboard loads, sensors shown, auto-refreshes | PASS
Manual pump ON via web | Click ON button in dashboard | Pump activates, pumpMode set to 1 | PASS
Manual pump OFF via web | Click OFF button in dashboard | Pump stops, pumpMode set to 2 | PASS
AUTO mode via web | Click AUTO button in dashboard | Returns to soil-threshold control | PASS

## 7.2 Integrated System Test

A full 30-minute continuous operation test was conducted with all components connected simultaneously. Key observations:

- Sensor readings updated reliably every 1 second with no missed cycles across the test period
- Web dashboard remained accessible throughout with auto-refresh functioning correctly
- Pump cycled ON and OFF correctly in AUTO mode as soil moisture changed over the watering cycle
- All five OLED emotion states triggered correctly in their respective scenarios
- Telegram alerts fired for low water and dry soil conditions with correct cooldown behaviour
- No Wi-Fi disconnections or system crashes observed during the 30-minute test window
- Serial Monitor output confirmed correct sensor values and pump state at all times

# 8. Challenges Faced

Challenge | Description | Solution
DHT11 NaN reads | DHT11 returns NaN on first read after boot and intermittently under electrical noise. | Added isnan() guard before assigning values; the last valid reading is retained if a new read fails.
HC-SR04 infinite block | Without a timeout, pulseIn() blocks the entire loop indefinitely when the tank is empty and no echo returns. | Added 30000 µs (30ms) timeout parameter; waterLevel is set to -1 on timeout and the dashboard shows 'No Echo'.
Relay floating at boot | GPIO 15 floats LOW briefly at boot, causing the relay to activate and the pump to turn ON unexpectedly. | Added explicit digitalWrite(RELAY_PIN, RELAY_OFF) as the very first action in setup() before any other initialisation.
Telegram TLS failure | ESP32 HTTPClient with full TLS certificate verification fails against api.telegram.org due to missing root CA store. | Used WiFiClientSecure with setInsecure() which skips certificate verification — acceptable for a trusted local IoT device.
HTML string memory spike | Building one large HTML string caused heap fragmentation and occasional crashes on early firmware builds. | Refactored to R"rawliteral()" raw string literals and split generation into smaller concatenated chunks to reduce peak RAM allocation.
OLED display flickering | Competing sensor data and emotion display code both called display.clearDisplay() in the same loop, causing visible flicker. | Introduced the emotionUntil timer system; emotion display takes exclusive priority and sensor data only renders when currentEmotion == NONE.
Soil sensor calibration | ADC values varied significantly between sensors of the same model and with different soil compositions and moisture levels. | Exposed threshold as a top-level configurable variable and documented a calibration procedure in the README.

# 9. Future Improvements

Improvement | Priority | Description
MQTT / Home Assistant | High | Publish sensor readings to an MQTT broker for integration with Home Assistant, Node-RED, or Grafana dashboards.
OTA Firmware Updates | High | Enable ArduinoOTA so the device can receive firmware updates over Wi-Fi without physical USB access.
Firebase Data Logging | Medium | Push timestamped readings to Firebase Realtime Database for long-term historical analysis and trend graphs.
Daily Telegram Summary | Medium | Send a daily summary at a scheduled time with min/max/average values for all sensors using NTP time.
SD Card CSV Logging | Medium | Log all sensor readings to microSD as CSV for offline analysis and resilience against Wi-Fi loss.
Custom PCB + Enclosure | Medium | Design a production-grade two-layer PCB in EasyEDA and a 3D-printed weatherproof enclosure.
Solar + Battery Backup | Low | Add LiPo battery with TP4056 charging and a small solar panel for fully off-grid autonomous operation.
Multi-Zone Irrigation | Low | Support multiple soil sensors and relays for independent control of several plant zones.
REST API Endpoint | Low | Expose a JSON API so Google Home, Alexa, or custom mobile apps can query sensor values and control the pump.
Voice Assistant | Low | Integrate with Google Home / Amazon Alexa via the REST API for voice-controlled irrigation commands.

# 10. Project Images, Demo Video & Submission Links

## 10.1 Project Images

All project photographs and screenshots are stored in the /images/ folder of the GitHub repository and in the Google Drive submission folder.

Images submitted include:

• Full assembled circuit on breadboard

• OLED emotion display — all 5 states (GREETING, HAPPY, SAD, LAUGHING, SLEEPY)

• Web dashboard screenshot on mobile and desktop browsers

• Telegram bot alert notification screenshot

• EasyEDA PCB layout render (top and bottom copper layers)

## 10.2 Demo Video

A full demonstration video showing the system operating in real time — including auto-watering triggering, all emotion transitions, the live web dashboard, and Telegram alerts firing — is available at:

Demo Video: https://drive.google.com/drive/folders/1ZfgRjcn0nLJQALMsFx7dsPL00-i2h-ok?usp=sharing

## 10.3 Submission Links

Deliverable | Link
GitHub Repository | https://github.com/Ninad-Hazarika/smart-plant-monitoring-system
Google Drive Folder | https://drive.google.com/drive/folders/1ZfgRjcn0nLJQALMsFx7dsPL00-i2h-ok?usp=sharing
LinkedIn | www.linkedin.com/in/ninad-hazarika-14a27937a

## 10.4 References

1. Espressif Systems. ESP32 Technical Reference Manual. https://docs.espressif.com/
2. Adafruit Industries. Adafruit SSD1306 Library. https://github.com/adafruit/Adafruit_SSD1306
3. Adafruit Industries. DHT Sensor Library. https://github.com/adafruit/DHT-sensor-library
4. Telegram. Bot API Documentation. https://core.telegram.org/bots/api
5. Arduino. Language Reference. https://www.arduino.cc/reference/en/
6. EasyEDA. Online PCB Design Tool. https://easyeda.com/
7. JLCPCB. PCB Fabrication Service. https://jlcpcb.com/

# 11. PCB Design & CAD Files

## 11.1 PCB Design

The printed circuit board was designed using EasyEDA (https://easyeda.com/), a free browser-based PCB design tool with direct one-click ordering integration for JLCPCB.

- PCB project files (.json) are located in /pcb/ on the GitHub repository
- Gerber files for fabrication are packaged as /pcb/gerber.zip
- The board consolidates all sensor headers, relay footprint, OLED header, and ESP32 DevKit socket on a single compact board
- Can be fabricated at JLCPCB for approximately $2 USD per 5-board order
- Minimum trace width 0.3 mm; two copper layers; HAL surface finish

## 11.2 CAD / Enclosure Design

A 3D-printed weatherproof enclosure is planned for v3.0. The current prototype uses an open breadboard assembly. CAD files (Fusion 360 / FreeCAD .f3d / .FCStd) will be added to the /cad/ folder in the next release.

## 11.3 Schematic Files

EasyEDA circuit schematics (.json native format and exported .svg) are located in the /schematics/ folder. The schematic covers all nine peripheral connections to the ESP32 DevKit including power rail annotations, GPIO labels, and component values.

Project Summary

Item | Detail
Project Name | Smart Plant Monitoring System
Author | Ninad Hazarika — ninadhazarika@gmail.com
MCU | ESP32 DevKit v1 (Dual-core LX6, 240 MHz, Wi-Fi + BT)
Sensors | DHT11, Capacitive Soil, HC-SR04 Ultrasonic, IR, Touch
Actuators | 5V Relay, Mini DC Water Pump, Passive Buzzer
Display | OLED SSD1306 — 0.96", 128x64, I2C @ 0x3C
Connectivity | Wi-Fi 802.11 b/g/n — local HTTP server port 80
Notifications | Telegram Bot — HTTPS push (5 distinct alert types)
Pump Modes | AUTO (soil threshold) / MANUAL ON / MANUAL OFF
Emotion Engine | 5 states: GREETING / HAPPY / SAD / LAUGHING / SLEEPY
Web Dashboard | Responsive dark-theme UI, 2-second auto-refresh
Alert Cooldowns | 30s global Telegram cooldown; 5s for human detection
Language | C++ (Arduino Framework) + HTML/CSS/JS (web UI)
License | MIT Open Source
GitHub | github.com/ninadhazarika/smart-plant-monitoring-system

"Plants can't talk — so we built something that does."

ESP32 IoT Plant Care System Page

Smart Plant Monitoring System | Project Report | Ninad Hazarika

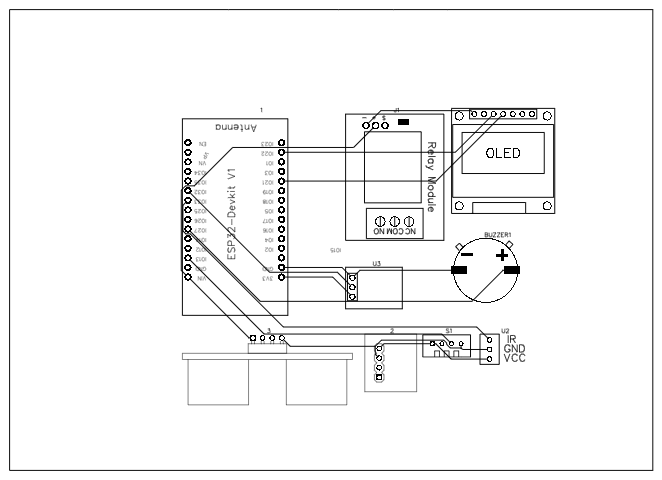
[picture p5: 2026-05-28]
smart-plant-monitoring-system/pcb/pcb_overview.png

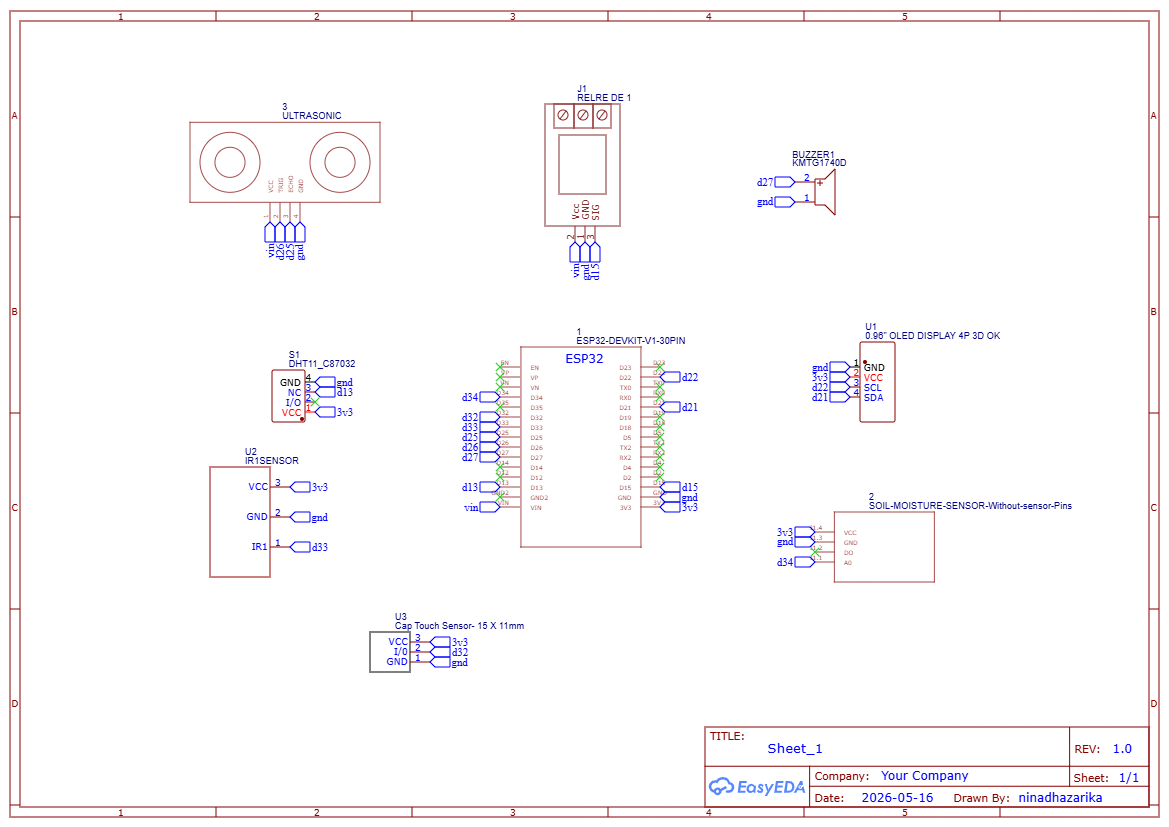
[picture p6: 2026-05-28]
smart-plant-monitoring-system/schematics/Schematic_Smart-Irrigation-System_2026-05-28.png

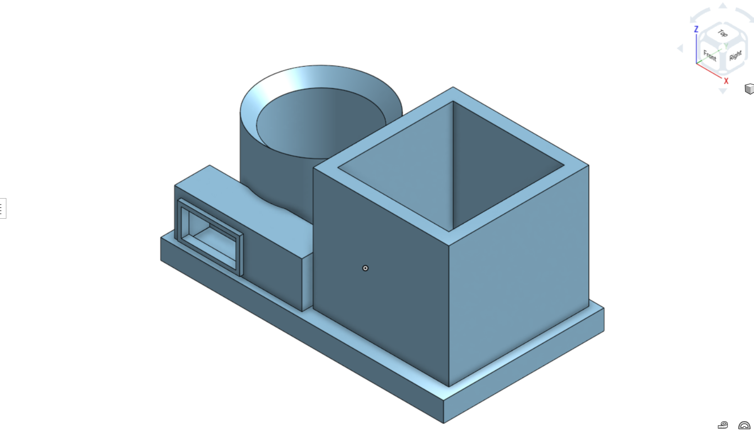
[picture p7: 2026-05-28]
smart-plant-monitoring-system/CAD-Design/isometric-view.png

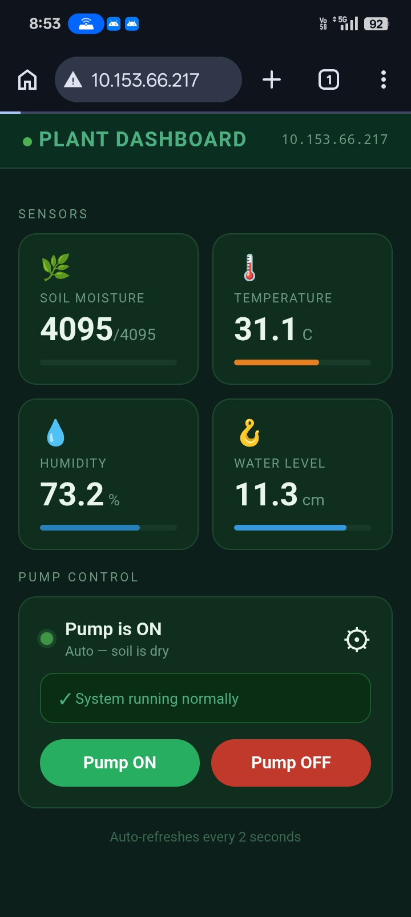
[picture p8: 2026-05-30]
smart-plant-monitoring-system/Images/website.jpeg

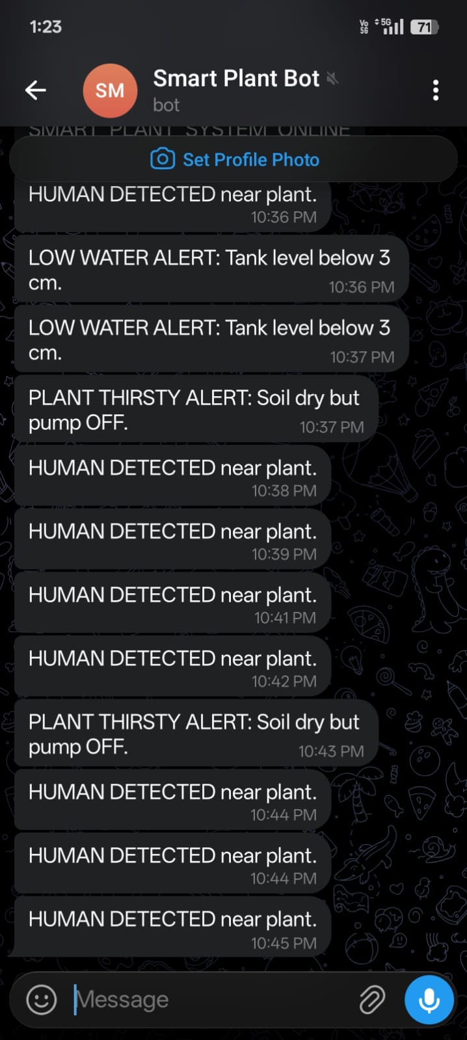
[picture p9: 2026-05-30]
smart-plant-monitoring-system/Images/telegram_bot.jpeg

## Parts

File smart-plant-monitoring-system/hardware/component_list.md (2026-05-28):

# Component List — Smart Plant Monitoring System

## Core Components

| Component | Spec | Qty | Notes |
|---|---|:---:|---|
| ESP32 DevKit v1 | Dual-core, 240MHz, Wi-Fi + BT | 1 | Any ESP32 DevKit works |
| DHT11 Sensor | 0–50°C, 20–90% RH | 1 | DHT22 for better accuracy |
| Soil Moisture Sensor | Analog resistive/capacitive | 1 | Capacitive preferred (no corrosion) |
| OLED Display | SSD1306, 0.96", I2C, 128×64 | 1 | I2C address: 0x3C |
| 5V Relay Module | Single channel, active LOW | 1 | Most modules are active LOW |
| Mini DC Water Pump | 3V–6V, submersible | 1 | Powered by external supply |

## Power & Passives

| Component | Spec | Qty | Notes |
|---|---|:---:|---|
| 9V Battery or DC Adapter | For pump power | 1 | Do not power pump from ESP32 |
| Micro USB Cable | For ESP32 power + programming | 1 | |
| Jumper Wires | M-M, M-F | ~20 | Assorted |
| Breadboard | 830 tie-point | 1 | Or use custom PCB |

## Optional / Expansion

| Component | Spec | Qty | Purpose |
|---|---|:---:|---|
| Ultrasonic Sensor | HC-SR04 | 1 | Water tank level monitoring |
| Buzzer | 5V passive | 1 | Audio alerts |
| LED + 220Ω Resistor | Any color | 1 | Status indicator |
| SD Card Module | SPI | 1 | Data logging |
| LiPo Battery + TP4056 | For battery backup | 1 | Portable operation |

## Where to Buy

- [Robu.in](https://robu.in/) — India, fast shipping
- [AliExpress](https://aliexpress.com/) — Cheapest, 2–4 week shipping
- [Amazon India](https://amazon.in/) — Convenient, Prime eligible

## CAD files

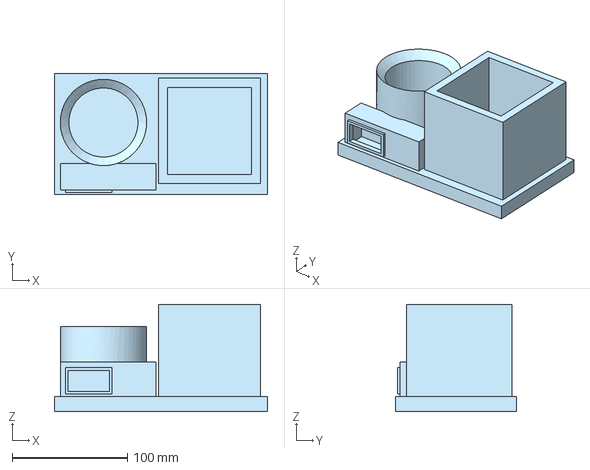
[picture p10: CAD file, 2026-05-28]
smart-plant-monitoring-system/CAD-Design/Final Assembly.step
185.0 x 105.0 x 93.0 mm

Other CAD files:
smart-plant-monitoring-system/CAD-Design/Final Assembly.stl

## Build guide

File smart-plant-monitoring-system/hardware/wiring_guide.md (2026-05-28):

# Wiring Guide — Smart Plant Monitoring System

> ⚠️ **Safety First:** Always disconnect power before changing wiring. Never connect the pump directly to ESP32 GPIO pins.

---

## 1. DHT11 Temperature & Humidity Sensor

| DHT11 Pin | Connect To |
|---|---|
| VCC | ESP32 3.3V |
| GND | ESP32 GND |
| OUT / Data | ESP32 GPIO 13 |

*If your DHT11 module doesn't have a built-in pull-up resistor, add a 10kΩ resistor between VCC and DATA pin.*

---

## 2. Soil Moisture Sensor

| Sensor Pin | Connect To |
|---|---|
| VCC | ESP32 3.3V |
| GND | ESP32 GND |
| AO (Analog Out) | ESP32 GPIO 34 |

*GPIO 34 is an input-only pin — perfect for analog readings. Do not connect DO (digital out) unless you want a simple threshold trigger.*

---

## 3. OLED Display (SSD1306, I2C)

| OLED Pin | Connect To |
|---|---|
| VCC | ESP32 3.3V |
| GND | ESP32 GND |
| SDA | ESP32 GPIO 21 |
| SCL | ESP32 GPIO 22 |

*Default I2C address is 0x3C. If display doesn't initialize, try 0x3D.*

---

## 4. Relay Module

| Relay Pin | Connect To |
|---|---|
| VCC | ESP32 5V / VIN |
| GND | ESP32 GND |
| IN | ESP32 GPIO 15 |

*Most relay modules are active LOW — the relay activates when IN is pulled LOW. The firmware already handles this (`RELAY_ON = LOW`).*

---

## 5. Water Pump via Relay

```
  9V Battery (+) ──────▶ Relay COM
  Relay NO ────────────▶ Pump (+)
  Pump (–) ────────────▶ 9V Battery (–)
  9V Battery (–) ──────▶ ESP32 GND  (common ground)
```

> **COM** = Common terminal  
> **NO** = Normally Open (pump is OFF when relay is OFF)  
> **NC** = Normally Closed (pump is ON when relay is OFF — don't use this)

---

## Quick Reference Diagram

```
ESP32          DHT11        Soil Sensor     OLED          Relay
──────         ─────        ───────────     ────          ─────
3.3V  ────────▶ VCC          VCC    ◀────── 3.3V          VCC ◀── 5V/VIN
GND   ────────▶ GND          GND    ◀────── GND           GND ◀── GND
GPIO13 ───────▶ OUT          AO     ◀────── GPIO34        IN  ◀── GPIO15
GPIO21 ─────────────────────────────────── SDA
GPIO22 ─────────────────────────────────── SCL
3.3V  ─────────────────────────────────── VCC
GND   ─────────────────────────────────── GND
```

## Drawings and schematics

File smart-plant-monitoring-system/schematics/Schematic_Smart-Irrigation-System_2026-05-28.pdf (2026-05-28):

A | A

1

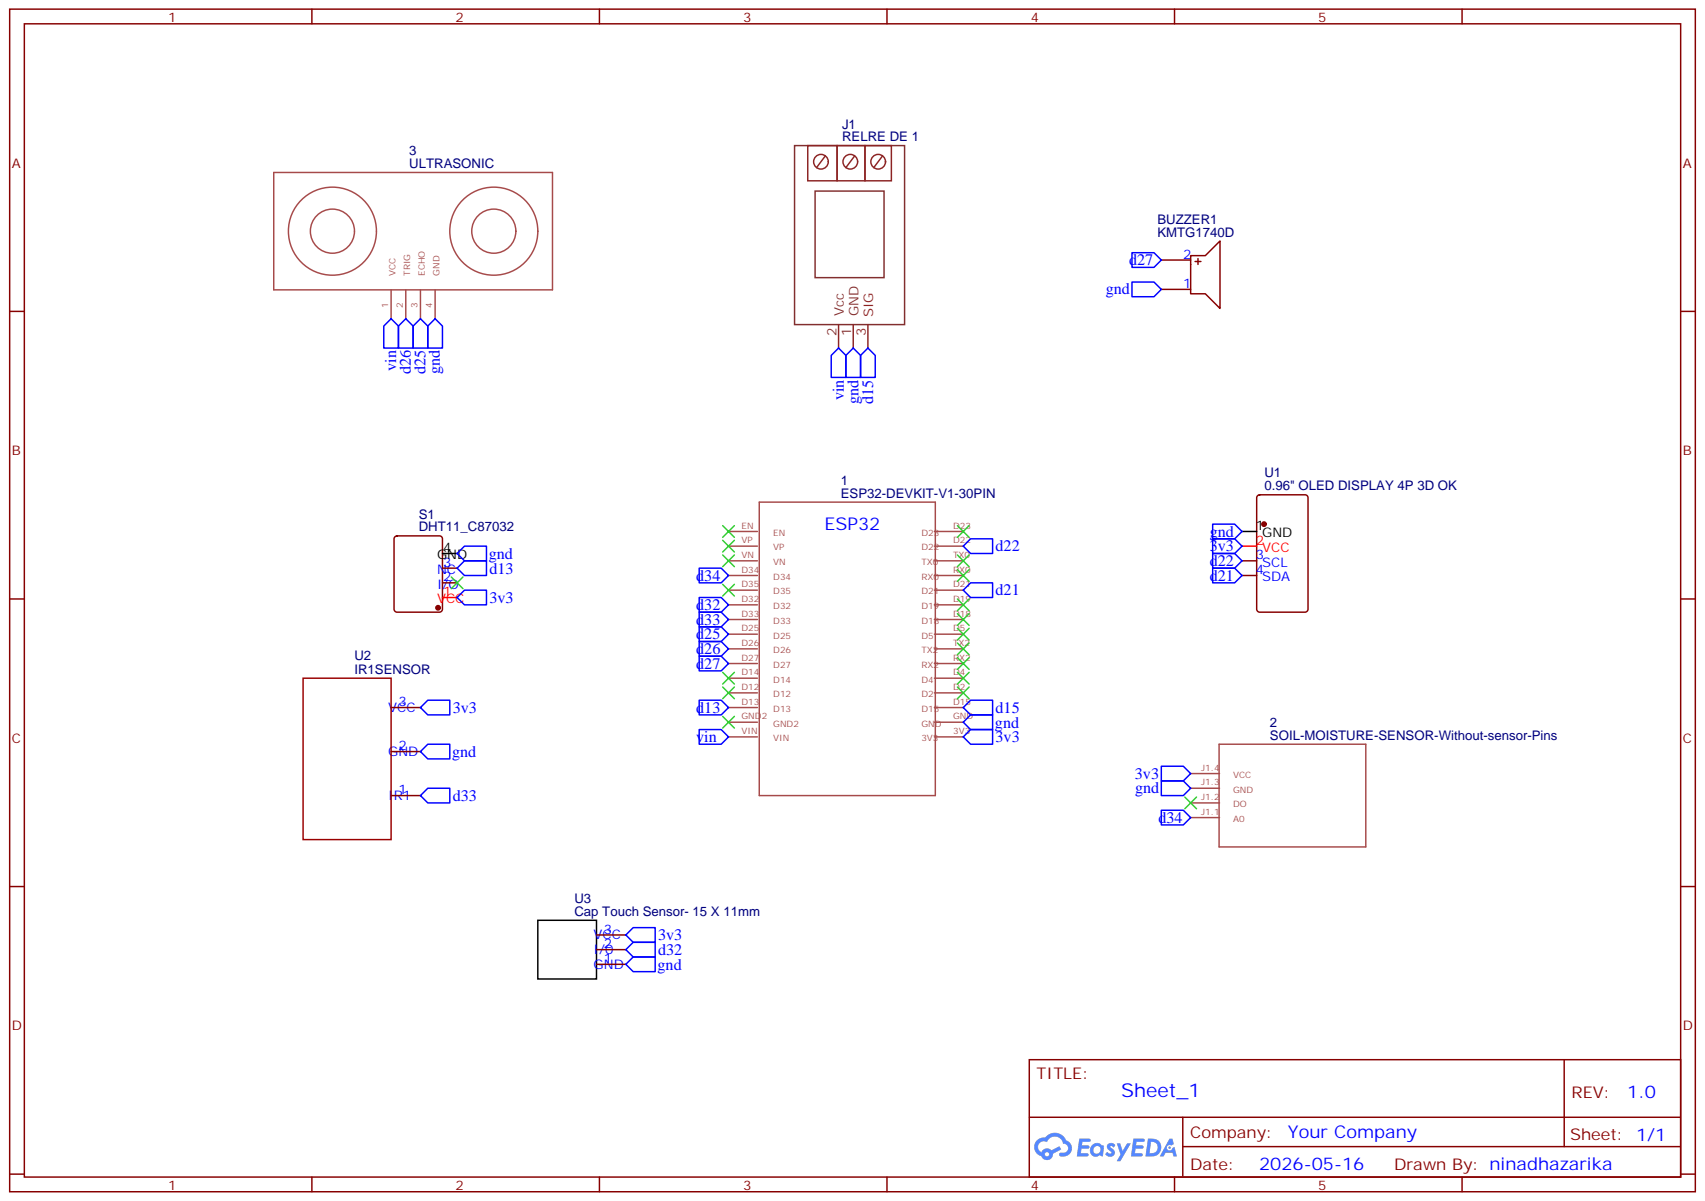
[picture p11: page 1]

SOIL-MOISTURE-SENSOR-Without-sensor-Pins

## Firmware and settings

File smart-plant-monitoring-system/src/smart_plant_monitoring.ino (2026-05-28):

#include <WiFi.h>
#include <WebServer.h>
#include <WiFiClientSecure.h>
#include <HTTPClient.h>
#include <Wire.h>
#include <Adafruit_GFX.h>
#include <Adafruit_SSD1306.h>
#include <DHT.h>

// ================= WIFI =================
const char* ssid     = "YOUR_WIFI_NAME";
const char* password = "YOUR_WIFI_PASSWORD";

WebServer server(80);

// ================= TELEGRAM =================
String botToken = "YOUR_BOT_TOKEN";
String chatID   = "YOUR_CHAT_ID";

// ================= OLED =================
#define SCREEN_WIDTH 128
#define SCREEN_HEIGHT 64
#define OLED_RESET -1
Adafruit_SSD1306 display(SCREEN_WIDTH, SCREEN_HEIGHT, &Wire, OLED_RESET);

// ================= PINS =================
#define DHTPIN      13
#define DHTTYPE     DHT11
#define SOIL_PIN    34
#define RELAY_PIN   15
#define TRIG_PIN    26
#define ECHO_PIN    25
#define BUZZER_PIN  27
#define IR_PIN      33
#define TOUCH_PIN   32

DHT dht(DHTPIN, DHTTYPE);

// ================= SETTINGS =================
int   threshold  = 3000;   // ADC value above which soil is "dry"
float tankHeight = 13.7;   // Height of water tank in cm

#define RELAY_ON  LOW
#define RELAY_OFF HIGH

// 0 = AUTO, 1 = MANUAL ON, 2 = MANUAL OFF
int pumpMode = 0;

// ================= SENSOR VALUES =================
int   soilValue  = 0;
float temperature = 0;
float humidity   = 0;
float waterLevel = 0;
bool  pumpState  = false;

// ================= TIMERS =================
unsigned long lastSensorRead      = 0;
unsigned long lastTelegramAlert   = 0;
unsigned long telegramCooldown    = 30000;
unsigned long lastHumanAlertTime  = 0;
unsigned long humanAlertCooldown  = 5000;
unsigned long pumpStartTime       = 0;
unsigned long dryStartTime        = 0;

bool lowWaterAlertSent  = false;
bool pumpLongAlertSent  = false;
bool thirstyAlertSent   = false;

int  humanDetectCount = 0;

// ================= OLED EMOTION ENGINE =================
enum Emotion { NONE, GREETING, HAPPY, SAD, LAUGHING, SLEEPY };

Emotion       currentEmotion  = NONE;
unsigned long emotionUntil    = 0;
unsigned long lastHumanSeen   = 0;
unsigned long lastSadReminder = 0;
unsigned long lastTouchTime   = 0;
int           touchCount      = 0;
bool          lastTouchState  = LOW;
bool          lastIRState     = HIGH;

// ================= URL ENCODE =================
String urlEncode(String text) {
  text.replace("%",  "%25");
  text.replace(" ",  "%20");
  text.replace("\n", "%0A");
  text.replace(":",  "%3A");
  text.replace("/",  "%2F");
  text.replace("?",  "%3F");
  text.replace("&",  "%26");
  return text;
}

// ================= TELEGRAM =================
void sendTelegramMessage(String message) {
  if (WiFi.status() != WL_CONNECTED) return;

  WiFiClientSecure client;
  client.setInsecure();

  HTTPClient https;
  https.setTimeout(15000);

  String url = "https://api.telegram.org/bot" + botToken +
               "/sendMessage?chat_id=" + chatID +
               "&text=" + urlEncode(message);

  if (!https.begin(client, url.c_str())) {
    Serial.println("HTTPS begin failed");
    return;
  }

  int httpCode = https.GET();
  Serial.print("Telegram response: ");
  Serial.println(httpCode);
  https.end();
}

// ================= WEB DASHBOARD =================
String makeWebPage() {
  String pumpText = pumpState ? "Pump is ON" : "Pump is OFF";
  String modeText;
  if      (pumpMode == 0) modeText = "AUTO MODE";
  else if (pumpMode == 1) modeText = "MANUAL ON";
  else                    modeText = "MANUAL OFF";

  String html = R"rawliteral(
<!DOCTYPE html><html>
<head>
<meta charset="UTF-8">
<meta name="viewport" content="width=device-width, initial-scale=1">
<title>Smart Plant Dashboard</title>
<style>
*{box-sizing:border-box;margin:0;padding:0}
body{font-family:Arial,sans-serif;background:#0d1f1a;color:#e8f5e9;min-height:100vh}
.topbar{background:#0a2e20;border-bottom:1px solid #1a4a30;padding:14px 20px;display:flex;align-items:center;justify-content:space-between}
.topbar-title{font-size:18px;font-weight:700;letter-spacing:1px;color:#4caf80}
.topbar-ip{font-size:12px;color:#6a9a80;font-family:monospace}
.main{padding:16px}
.section-label{font-size:11px;letter-spacing:2px;color:#6a9a80;text-transform:uppercase;margin:18px 0 10px}
.grid2{display:grid;grid-template-columns:1fr 1fr;gap:12px}
.card{background:#0f2e1e;border:1px solid #1e4a30;border-radius:16px;padding:16px}
.card-label{font-size:11px;color:#6a9a80;letter-spacing:1px;text-transform:uppercase}
.card-value{font-size:28px;font-weight:700;margin-top:4px;color:#e8f5e9}
.card-unit{font-size:14px;color:#6a9a80;font-weight:400}
.progress-bar{height:5px;border-radius:3px;background:#1a3a28;margin-top:10px;overflow:hidden}
.progress-fill{height:100%;border-radius:3px}
.pump-card{background:#0f2e1e;border:1px solid #1e4a30;border-radius:16px;padding:18px}
.pump-label{font-size:18px;font-weight:700}
.pump-sub{font-size:13px;color:#6a9a80;margin-top:4px}
.btn-row{display:flex;gap:10px;margin-top:14px}
.btn{flex:1;padding:12px 8px;border:none;border-radius:40px;font-size:14px;font-weight:600;text-decoration:none;text-align:center;color:white}
.btn-on{background:#27ae60}.btn-off{background:#c0392b}.btn-auto{background:#2980b9}
.warn-box{background:#2a1a00;border:1px solid #5a3800;border-radius:12px;padding:12px;margin-top:12px;font-size:13px;color:#f0a000}
.ok-box{background:#0a2e14;border:1px solid #1a5a28;border-radius:12px;padding:12px;margin-top:12px;font-size:13px;color:#4caf80}
.footer{text-align:center;font-size:12px;color:#3a6a50;padding:18px 0 10px}
</style>
</head>
<body>
<div class="topbar">
<div class="topbar-title">SMART PLANT DASHBOARD</div>
<div class="topbar-ip">)rawliteral";

  html += WiFi.localIP().toString();

  html += R"rawliteral(</div></div>
<div class="main">
<div class="section-label">Sensors</div>
<div class="grid2">)rawliteral";

  int soilPct = map(constrain(soilValue, 0, 4095), 0, 4095, 100, 0);
  html += "<div class='card'><div class='card-label'>Soil Moisture</div>";
  html += "<div class='card-value'>" + String(soilValue) + "<span class='card-unit'>/4095</span></div>";
  html += "<div class='progress-bar'><div class='progress-fill' style='width:" + String(soilPct) + "%;background:#27ae60'></div></div></div>";

  int tempPct = constrain(map((int)temperature, 0, 50, 0, 100), 0, 100);
  html += "<div class='card'><div class='card-label'>Temperature</div>";
  html += "<div class='card-value'>" + String(temperature, 1) + "<span class='card-unit'> C</span></div>";
  html += "<div class='progress-bar'><div class='progress-fill' style='width:" + String(tempPct) + "%;background:#e67e22'></div></div></div>";

  int humPct = constrain((int)humidity, 0, 100);
  html += "<div class='card'><div class='card-label'>Humidity</div>";
  html += "<div class='card-value'>" + String(humidity, 1) + "<span class='card-unit'> %</span></div>";
  html += "<div class='progress-bar'><div class='progress-fill' style='width:" + String(humPct) + "%;background:#2980b9'></div></div></div>";

  html += "<div class='card'><div class='card-label'>Water Level</div>";
  if (waterLevel == -1) {
    html += "<div class='card-value' style='font-size:18px;color:#888'>No Echo</div>";
  } else {
    int waterPct = constrain((int)((waterLevel / tankHeight) * 100), 0, 100);
    html += "<div class='card-value'>" + String(waterLevel, 1) + "<span class='card-unit'> cm</span></div>";
    html += "<div class='progress-bar'><div class='progress-fill' style='width:" + String(waterPct) + "%;background:#3498db'></div></div>";
  }
  html += "</div></div>";

  html += "<div class='section-label'>Pump Control</div>";
  html += "<div class='pump-card'>";
  html += "<div class='pump-label'>" + pumpText + "</div>";
  html += "<div class='pump-sub'>" + modeText + "</div>";

  if (waterLevel != -1 && waterLevel <= 3)
    html += "<div class='warn-box'>⚠ Water tank is low — refill soon</div>";
  else
    html += "<div class='ok-box'>✅ System running normally</div>";

  html += "<div class='btn-row'>";
  html += "<a href='/pump/on'   class='btn btn-on'>ON</a>";
  html += "<a href='/pump/off'  class='btn btn-off'>OFF</a>";
  html += "<a href='/pump/auto' class='btn btn-auto'>AUTO</a>";
  html += "</div></div>";

  html += "<div class='footer'>Auto-refreshes every 2 seconds</div>";
  html += R"rawliteral(</div>
<script>setTimeout(function(){location.reload();},2000);</script>
</body></html>)rawliteral";

  return html;
}

// ================= WEB HANDLERS =================
void handleRoot()    { server.send(200, "text/html", makeWebPage()); }
void handlePumpOn()  { pumpMode = 1; currentEmotion = HAPPY; emotionUntil = millis() + 3000; server.sendHeader("Location", "/"); server.send(303); }
void handlePumpOff() { pumpMode = 2; server.sendHeader("Location", "/"); server.send(303); }
void handleAuto()    { pumpMode = 0; server.sendHeader("Location", "/"); server.send(303); }

// ================= SENSOR READS =================
void readSoil() { soilValue = analogRead(SOIL_PIN); }

void readDHT() {
  float t = dht.readTemperature();
  float h = dht.readHumidity();
  if (!isnan(t)) temperature = t;
  if (!isnan(h)) humidity = h;
}

void readWaterLevel() {
  digitalWrite(TRIG_PIN, LOW);
  delayMicroseconds(2);
  digitalWrite(TRIG_PIN, HIGH);
  delayMicroseconds(10);
  digitalWrite(TRIG_PIN, LOW);

  long duration = pulseIn(ECHO_PIN, HIGH, 30000);
  if (duration == 0) { waterLevel = -1; return; }

  float distance = duration * 0.034 / 2;
  waterLevel = tankHeight - distance;
  if (waterLevel < 0) waterLevel = 0;
}

// ================= PUMP CONTROL =================
void controlPump() {
  bool oldState = pumpState;

  if      (pumpMode == 1) { digitalWrite(RELAY_PIN, RELAY_ON);  pumpState = true;  }
  else if (pumpMode == 2) { digitalWrite(RELAY_PIN, RELAY_OFF); pumpState = false; }
  else {
    if (soilValue > threshold) { digitalWrite(RELAY_PIN, RELAY_ON);  pumpState = true;  }
    else                       { digitalWrite(RELAY_PIN, RELAY_OFF); pumpState = false; }
  }

  if (!oldState && pumpState) { currentEmotion = HAPPY; emotionUntil = millis() + 3000; }
}

// ================= BUZZER =================
void checkTankLevel() {
  if (waterLevel == -1) { digitalWrite(BUZZER_PIN, LOW); return; }
  if (waterLevel <= 3)  { digitalWrite(BUZZER_PIN, HIGH); delay(80); digitalWrite(BUZZER_PIN, LOW); }
  else                  { digitalWrite(BUZZER_PIN, LOW); }
}

// ================= IR + TOUCH =================
void handleIR() {
  bool irState = digitalRead(IR_PIN);
  if (irState == LOW) {
    lastHumanSeen = millis();
    if (lastIRState == HIGH) { currentEmotion = GREETING; emotionUntil = millis() + 3000; }
  }
  lastIRState = irState;
}

void handleTouch() {
  bool touchState = digitalRead(TOUCH_PIN);
  if (touchState == HIGH && lastTouchState == LOW) {
    if (millis() - lastTouchTime < 900) touchCount++;
    else touchCount = 1;
    lastTouchTime = millis();
    if (touchCount >= 3) { currentEmotion = LAUGHING; emotionUntil = millis() + 5000; touchCount = 0; }
  }
  lastTouchState = touchState;
}

// ================= OLED DRAWING =================
void drawOpenEyes()   { display.fillCircle(38,22,12,WHITE); display.fillCircle(90,22,12,WHITE); display.fillCircle(38,22,5,BLACK); display.fillCircle(90,22,5,BLACK); display.fillCircle(34,18,2,WHITE); display.fillCircle(86,18,2,WHITE); }
void drawHappyEyes()  { display.drawLine(28,25,36,17,WHITE); display.drawLine(36,17,46,25,WHITE); display.drawLine(78,25,86,17,WHITE); display.drawLine(86,17,96,25,WHITE); }
void drawSadEyes()    { display.drawLine(26,18,46,26,WHITE); display.drawLine(78,26,98,18,WHITE); display.fillCircle(38,34,2,WHITE); display.fillCircle(90,34,2,WHITE); }
void drawSleepyEyes() { display.drawLine(25,24,48,24,WHITE); display.drawLine(78,24,101,24,WHITE); display.setCursor(96,6); display.print("Z"); display.setCursor(106,0); display.print("z"); }
void drawLaughEyes()  { display.drawLine(28,27,36,17,WHITE); display.drawLine(36,17,46,27,WHITE); display.drawLine(78,27,86,17,WHITE); display.drawLine(86,17,96,27,WHITE); display.drawLine(50,40,58,46,WHITE); display.drawLine(58,46,70,46,WHITE); display.drawLine(70,46,78,40,WHITE); }

void showEmotion() {
  display.clearDisplay();
  display.setTextColor(WHITE);
  display.setTextSize(1);

  if      (currentEmotion == GREETING) { drawOpenEyes();   display.setCursor(43,48); display.print("Hello!"); }
  else if (currentEmotion == HAPPY)    { drawHappyEyes();  display.setCursor(22,48); display.print("Ahh... Water!"); }
  else if (currentEmotion == SAD)      { drawSadEyes();    display.setCursor(25,48); display.print("I'm thirsty"); }
  else if (currentEmotion == LAUGHING) { drawLaughEyes();  display.setCursor(38,54); display.print("Hehehe!"); }
  else if (currentEmotion == SLEEPY)   { drawSleepyEyes(); display.setCursor(48,48); display.print("Zzz..."); }

  display.display();
}

void showSensorData() {
  display.clearDisplay();
  display.setTextSize(1);
  display.setTextColor(WHITE);

  display.setCursor(0, 0);  display.print("Soil: ");  display.println(soilValue);
  display.setCursor(0,13);  display.print("Water: ");
  if (waterLevel == -1)     display.println("No Echo");
  else                      { display.print(waterLevel,1); display.println(" cm"); }
  display.setCursor(0,26);  display.print("Temp: ");  display.print(temperature,1); display.println(" C");
  display.setCursor(0,39);  display.print("Hum: ");   display.print(humidity,1);    display.println(" %");
  display.setCursor(0,52);  display.print("Pump: ");  display.print(pumpState ? "ON" : "OFF");
  display.display();
}

void updateOLED() {
  if (currentEmotion != NONE) {
    showEmotion();
    if (millis() > emotionUntil) currentEmotion = NONE;
  } else {
    showSensorData();
  }
}

// ================= TELEGRAM ALERTS =================
void checkTelegramAlerts() {
  if (millis() - lastTelegramAlert >= telegramCooldown) {
    if (waterLevel != -1 && waterLevel <= 3 && !lowWaterAlertSent) {
      sendTelegramMessage("💧 LOW WATER ALERT: Tank level below 3 cm. Please refill.");
      lowWaterAlertSent = true; lastTelegramAlert = millis();
    }
    if (waterLevel > 5) lowWaterAlertSent = false;

    if (pumpState) {
      if (pumpStartTime == 0) pumpStartTime = millis();
      if (millis() - pumpStartTime > 60000 && !pumpLongAlertSent) {
        sendTelegramMessage("⚠️ WARNING: Pump has been running for over 60 seconds.");
        pumpLongAlertSent = true; lastTelegramAlert = millis();
      }
    } else { pumpStartTime = 0; pumpLongAlertSent = false; }

    if (soilValue > threshold && !pumpState) {
      if (dryStartTime == 0) dryStartTime = millis();
      if (millis() - dryStartTime > 60000 && !thirstyAlertSent) {
        sendTelegramMessage("🌵 PLANT THIRSTY: Soil is dry but pump is OFF. Check system.");
        thirstyAlertSent = true; lastTelegramAlert = millis();
      }
    } else { dryStartTime = 0; thirstyAlertSent = false; }
  }

  if (digitalRead(IR_PIN) == LOW) {
    humanDetectCount++;
    if (humanDetectCount >= 2 && millis() - lastHumanAlertTime > humanAlertCooldown) {
      sendTelegramMessage("👤 HUMAN DETECTED near your plant.");
      lastHumanAlertTime = millis(); humanDetectCount = 0;
    }
  } else { humanDetectCount = 0; }
}

// ================= SETUP =================
void setup() {
  Serial.begin(115200);

  pinMode(RELAY_PIN,  OUTPUT); digitalWrite(RELAY_PIN, RELAY_OFF);
  pinMode(BUZZER_PIN, OUTPUT); digitalWrite(BUZZER_PIN, LOW);
  pinMode(SOIL_PIN,   INPUT);
  pinMode(TRIG_PIN,   OUTPUT);
  pinMode(ECHO_PIN,   INPUT);
  pinMode(IR_PIN,     INPUT);
  pinMode(TOUCH_PIN,  INPUT);

  dht.begin();

  if (!display.begin(SSD1306_SWITCHCAPVCC, 0x3C)) {
    Serial.println("OLED failed — check wiring and I2C address");
    while (1);
  }

  display.clearDisplay();
  display.setTextSize(1);
  display.setTextColor(WHITE);
  display.setCursor(0, 20);
  display.println("Smart Plant");
  display.println("Starting...");
  display.display();

  WiFi.begin(ssid, password);
  Serial.print("Connecting to Wi-Fi");
  while (WiFi.status() != WL_CONNECTED) { delay(500); Serial.print("."); }

  Serial.println();
  Serial.println("WiFi Connected!");
  Serial.print("Dashboard: http://");
  Serial.println(WiFi.localIP());

  configTime(0, 0, "pool.ntp.org", "time.nist.gov");
  delay(3000);

  server.on("/",          handleRoot);
  server.on("/pump/on",   handlePumpOn);
  server.on("/pump/off",  handlePumpOff);
  server.on("/pump/auto", handleAuto);
  server.begin();

  lastHumanSeen = millis();
  sendTelegramMessage("✅ SMART_PLANT_SYSTEM_ONLINE\nDashboard: http://" + WiFi.localIP().toString());
}

// ================= LOOP =================
void loop() {
  server.handleClient();
  handleIR();
  handleTouch();

  if (millis() - lastSensorRead > 1000) {
    readSoil();
    readDHT();
    readWaterLevel();
    controlPump();
    checkTankLevel();

    if (waterLevel != -1 && waterLevel <= 3 && millis() - lastSadReminder > 10000) {
      currentEmotion = SAD; emotionUntil = millis() + 3000; lastSadReminder = millis();
    }

    if (millis() - lastHumanSeen > 60000 && currentEmotion == NONE) {
      currentEmotion = SLEEPY; emotionUntil = millis() + 3000; lastHumanSeen = millis();
    }

    checkTelegramAlerts();

    Serial.printf("Soil:%d | Water:%.1f | Temp:%.1f | Hum:%.1f | Pump:%s | Mode:%d | IR:%d\n",
      soilValue, waterLevel, temperature, humidity,
      pumpState ? "ON" : "OFF", pumpMode, digitalRead(IR_PIN));

    lastSensorRead = millis();
  }

  updateOLED();
  delay(50);
}

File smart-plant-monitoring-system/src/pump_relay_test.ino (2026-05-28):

#define RELAY_PIN 15

#define RELAY_ON LOW
#define RELAY_OFF HIGH

void setup() {
  Serial.begin(115200);
  pinMode(RELAY_PIN, OUTPUT);
  digitalWrite(RELAY_PIN, RELAY_OFF);
  Serial.println("Relay test started");
}

void loop() {
  Serial.println("Pump / Relay ON");
  digitalWrite(RELAY_PIN, RELAY_ON);
  delay(3000);

  Serial.println("Pump / Relay OFF");
  digitalWrite(RELAY_PIN, RELAY_OFF);
  delay(3000);
}

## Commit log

2026-05-28 Rename Screenshot 2026-05-28 161903.png to pcb_bottom.png
2026-05-28 Rename Screenshot 2026-05-28 161856.png to pcb_top.png
